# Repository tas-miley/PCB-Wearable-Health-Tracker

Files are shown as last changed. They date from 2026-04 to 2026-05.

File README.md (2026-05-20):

# PCB-Wearable-Health-Tracker
PCB design to run the firmware for the Wearable Health Tracker project. The goal of this PCB is to support SPO2 and IMU sensors, BLE communication, and LiPo battery power/charging. It's also designed to be ~1 inch x 1 inch to support wrist wearability.

Completed:
- Component selection (Max30102, LSM6DSOX, nRF52833, voltage regulators)
- Battery Selection (LiPo 150mAh)
- Connector choice (USB-C for charging, battery connector, Tag Connect for programming)
- Initial 2 layer trace layout
- 

Todo:
- Move from 2 layer to 4 layer board, with GND and PWR planes

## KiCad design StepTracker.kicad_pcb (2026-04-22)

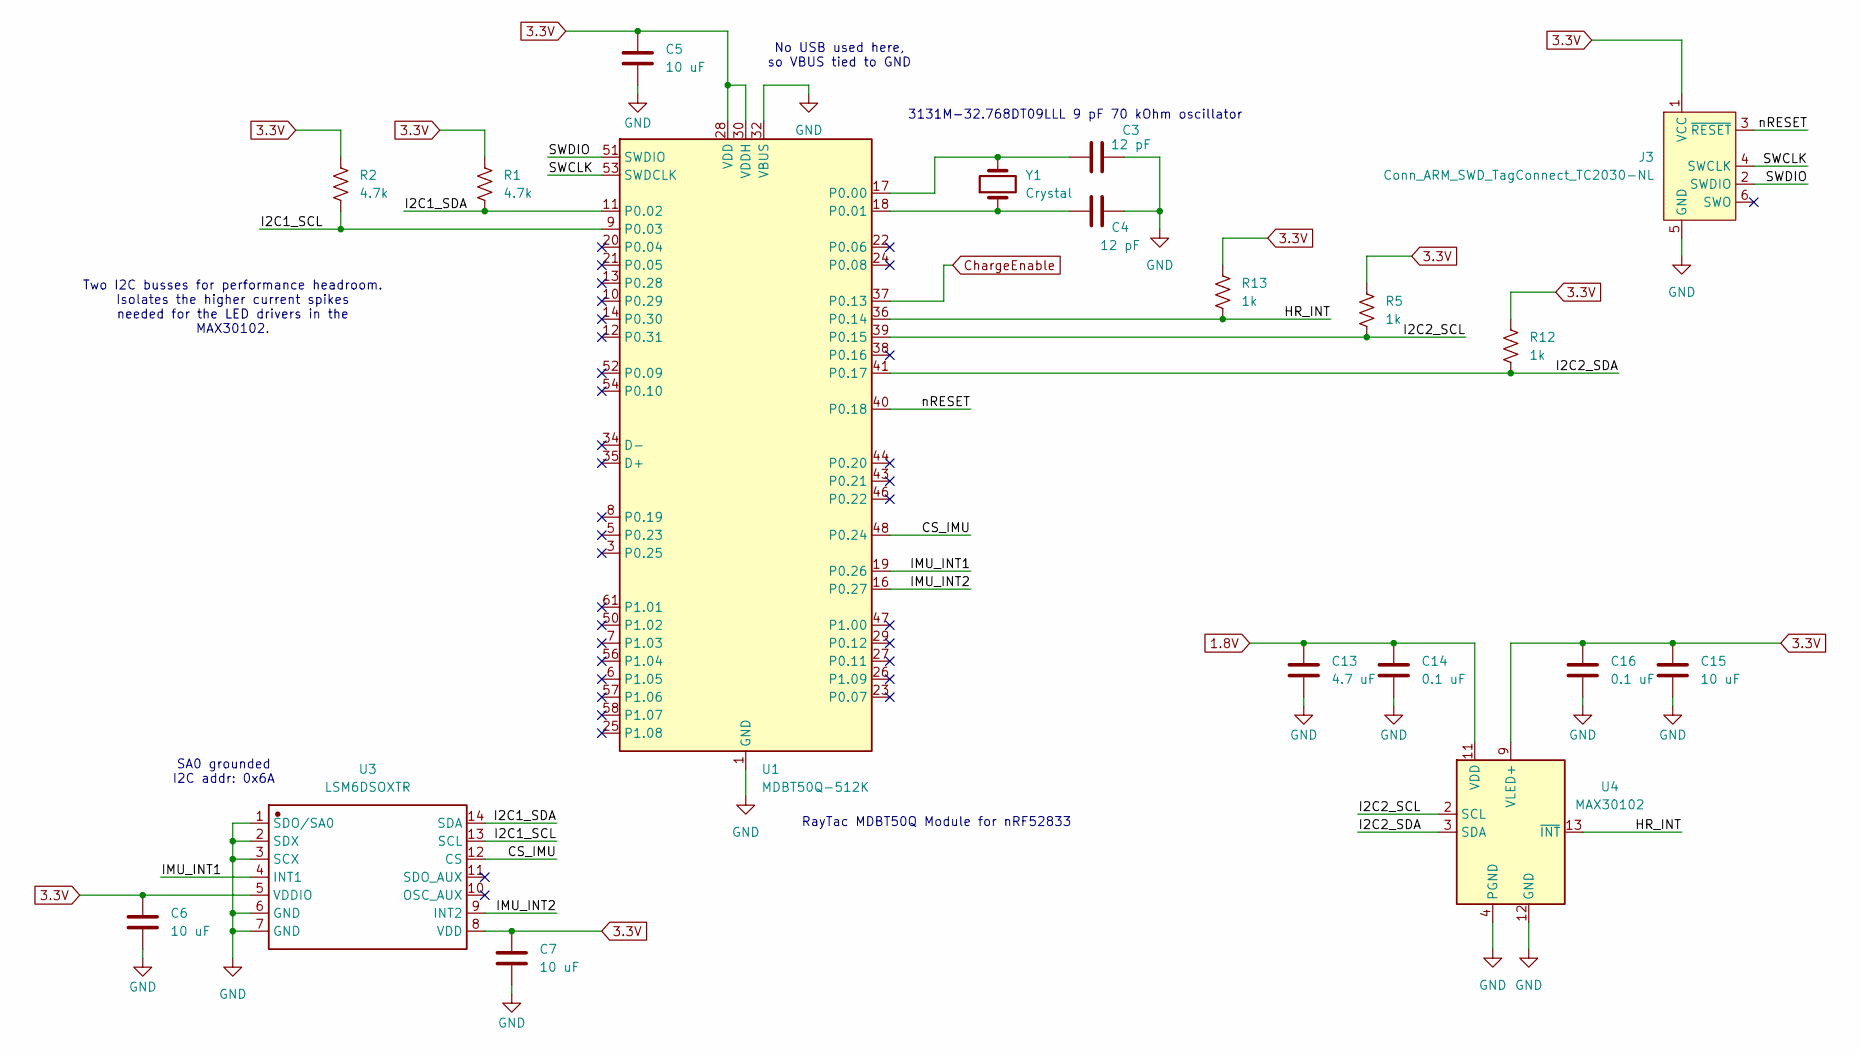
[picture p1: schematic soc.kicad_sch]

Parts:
C3, C4: 12 pF; C_0402
C5, C6, C7, C15: 10 uF; C_0402
C13: 4.7 uF; C_0402
C14, C16: 0.1 uF; C_0402
J3: Conn_ARM_SWD_TagConnect_TC2030-NL; Tag-Connect_TC2030-IDC-NL_2x03_P1.27mm_Vertical
R1, R2: 4.7k; R_0402
R5, R12, R13: 1k; R_0402
U1: MDBT50Q-512K; Raytac_MDBT50Q
U3: LSM6DSOXTR; LSM6DSOX; Manufacturer Part LSM6DSOXTR
U4: MAX30102; Maxim_OLGA-14_3.3x5.6mm_P0.8mm
Y1: Crystal; Crystal_3131M

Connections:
1.8V: C13.1, C14.1, U4.11 (VDD); also elsewhere on the board
3.3V: C5.1, C6.1, C7.1, C15.1, C16.2, J3.1 (VCC), R1.1, R2.1, R5.1, R12.1, R13.1, U1.28 (VDD), U1.30 (VDDH), U3.5 (VDDIO), U3.8 (VDD), U4.9 (VLED+), U4.10 (VLED+); also elsewhere on the board
/SOC/CS_IMU: U1.48 (P0.24), U3.12 (CS)
/SOC/HR_INT: R13.2, U1.36 (P0.14), U4.13 (~INT)
/SOC/I2C1_SCL: R2.2, U1.9 (P0.03), U3.13 (SCL)
/SOC/I2C1_SDA: R1.2, U1.11 (P0.02), U3.14 (SDA)
/SOC/I2C2_SCL: R5.2, U1.39 (P0.15), U4.2 (SCL)
/SOC/I2C2_SDA: R12.2, U1.41 (P0.17), U4.3 (SDA)
/SOC/IMU_INT1: U1.19 (P0.26), U3.4 (INT1)
/SOC/IMU_INT2: U1.16 (P0.27), U3.9 (INT2)
/SOC/SWCLK: J3.4 (SWCLK), U1.53 (SWDCLK)
/SOC/SWDIO: J3.2 (SWDIO), U1.51 (SWDIO)
/SOC/nRESET: J3.3 (~RESET), U1.40 (P0.18)
ChargeEnable: U1.37 (P0.13); also elsewhere on the board
GND: C3.2, C4.2, C5.2, C6.2, C7.2, C13.2, C14.2, C15.2, C16.1, J3.5 (GND), U1.1 (GND), U1.2 (GND), U1.15 (GND), U1.32 (VBUS), U1.33 (GND), U1.55 (GND), U3.1 (SDO/SA0), U3.2 (SDX), U3.3 (SCX), U3.6 (GND), U3.7 (GND), U4.4 (PGND), U4.12 (GND); also elsewhere on the board
unnamed: C3.1, U1.17 (P0.00), Y1.2
unnamed: C4.1, U1.18 (P0.01), Y1.1

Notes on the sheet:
3131M-32.768DT09LLL 9 pF 70 kOhm oscillator
Two I2C busses for performance headroom. Isolates the higher current spikes needed for the LED drivers in the MAX30102.
RayTac MDBT50Q Module for nRF52833
SA0 grounded I2C addr: 0x6A
No USB used here, so VBUS tied to GND

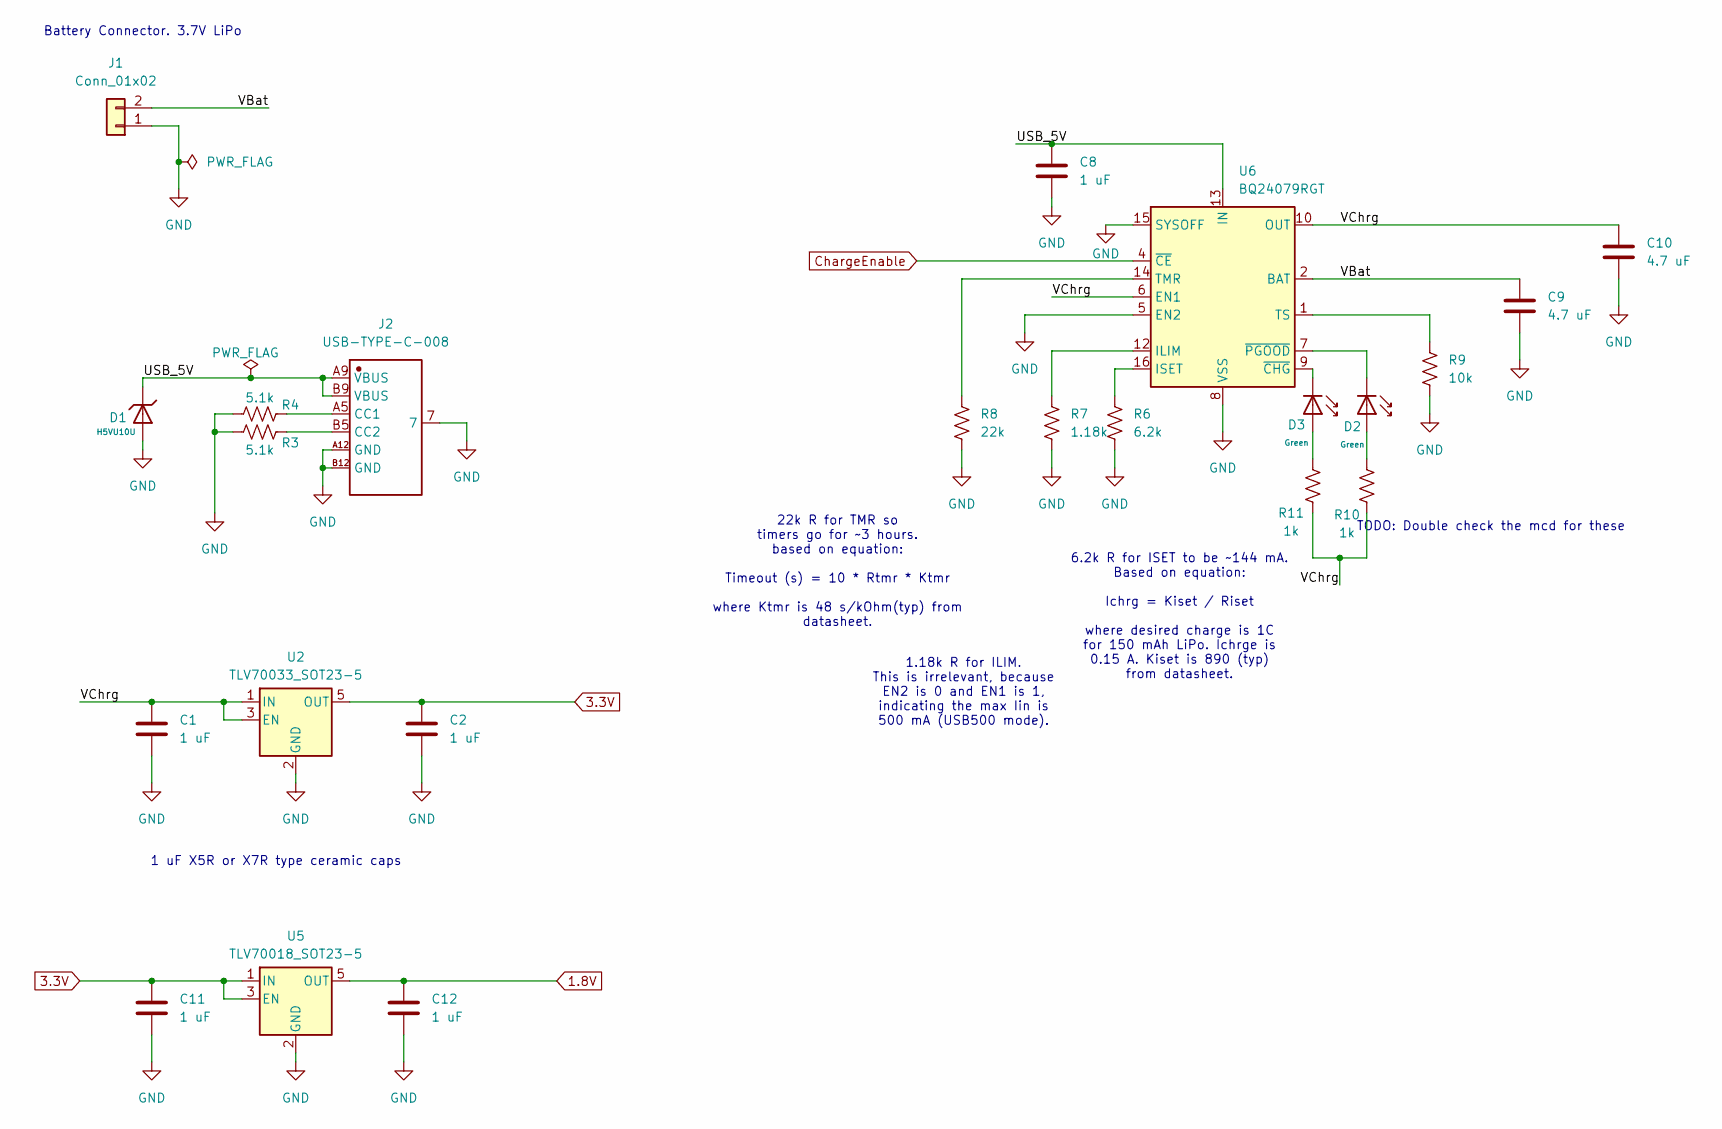
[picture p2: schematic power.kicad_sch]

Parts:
C1, C2, C8, C11, C12: 1 uF; C_0402
C9, C10: 4.7 uF; C_0402
D1: H5VU10U; D_DFN1006-2L; Breakdown Voltage 9V; Part H5VU10U; LCSC C22395519
D2, D3: Green; D_0805; Part KT-0805G; LCSC C2297
J1: Conn_01x02; JST_EH_S2B-EH_1x02_P2.50mm_Horizontal
J2: USB-TYPE-C-008; USB-C-SMD_TYPE-602-T3; Manufacturer Part USB-TYPE-C-008
R3, R4: 5.1k; R_0402
R6: 6.2k; R_0402
R7: 1.18k; R_0402
R8: 22k; R_0402
R9: 10k; R_0402
R10, R11: 1k; R_0402
U2: TLV70033_SOT23-5; SOT-23-5
U5: TLV70018_SOT23-5; SOT-23-5
U6: BQ24079RGT; VQFN-16-1EP_3x3mm_P0.5mm_EP1.6x1.6mm

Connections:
1.8V: C12.1, U5.5 (OUT); also elsewhere on the board
3.3V: C2.1, C11.1, U2.5 (OUT), U5.1 (IN), U5.3 (EN); also elsewhere on the board
/Power/USB_5V: C8.1, D1.1, J2.A9 (VBUS), J2.B9 (VBUS), U6.13 (IN)
/Power/VBat: C9.1, J1.2, U6.2 (BAT), U6.3 (BAT)
/Power/VChrg: C1.1, C10.1, R10.2, R11.2, U2.1 (IN), U2.3 (EN), U6.6 (EN1), U6.10 (OUT), U6.11 (OUT)
ChargeEnable: U6.4 (~CE); also elsewhere on the board
GND: C1.2, C2.2, C8.2, C9.2, C10.2, C11.2, C12.2, D1.2, J1.1, J2.7, J2.A12 (GND), J2.B12 (GND), R3.2, R4.2, R6.2, R7.2, R8.2, R9.2, U2.2 (GND), U5.2 (GND), U6.5 (EN2), U6.8 (VSS), U6.15 (SYSOFF), U6.17 (VSS); also elsewhere on the board
unnamed: D2.2, R10.1
unnamed: D3.2, R11.1
unnamed: J2.A5 (CC1), R4.1
unnamed: J2.B5 (CC2), R3.1
unnamed: R7.1, U6.12 (ILIM)
unnamed: R6.1, U6.16 (ISET)
unnamed: R8.1, U6.14 (TMR)
unnamed: R9.1, U6.1 (TS)
unnamed: D3.1, U6.9 (~CHG)
unnamed: D2.1, U6.7 (~PGOOD)

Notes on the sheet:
1.18k R for ILIM. This is irrelevant, because EN2 is 0 and EN1 is 1, indicating the max Iin is 500 mA (USB500 mode).
TODO: Double check the mcd for these
1 uF X5R or X7R type ceramic caps
22k R for TMR so timers go for ~3 hours. based on equation: Timeout (s) = 10 * Rtmr * Ktmr where Ktmr is 48 s/kOhm(typ) from datasheet.
6.2k R for ISET to be ~144 mA. Based on equation: Ichrg = Kiset / Riset where desired charge is 1C for 150 mAh LiPo. Ichrge is 0.15 A. Kiset is 890 (typ) from datasheet.
Battery Connector. 3.7V LiPo

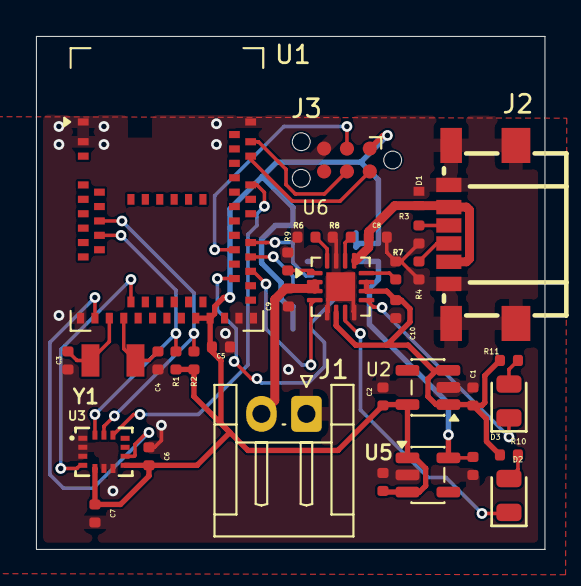
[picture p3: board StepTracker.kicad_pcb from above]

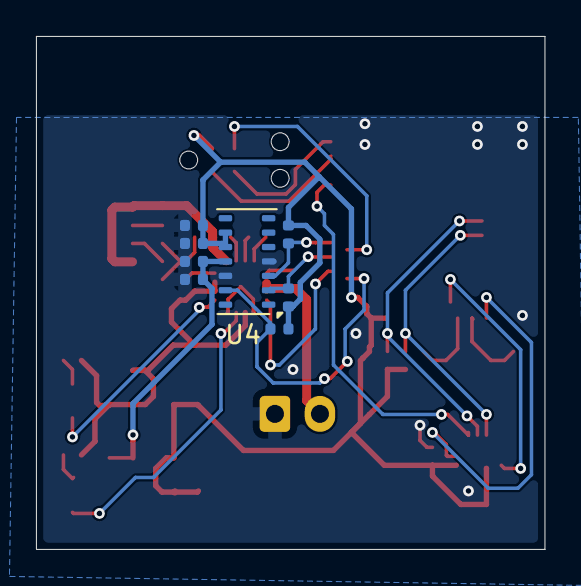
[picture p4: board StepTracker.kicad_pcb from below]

Board: 2 copper layers, 28.2 x 28.5 mm, 42 parts (8 on the bottom side), 30 nets.

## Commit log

2026-04-21 initial tracking of schematic and PCB layout
    [StepTracker.kicad_pcb, StepTracker.kicad_sch, power.kicad_sch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]
2026-04-22 update to include footprints from project specific lib
    [StepTracker.kicad_pcb, power.kicad_sch, soc.kicad_sch]
